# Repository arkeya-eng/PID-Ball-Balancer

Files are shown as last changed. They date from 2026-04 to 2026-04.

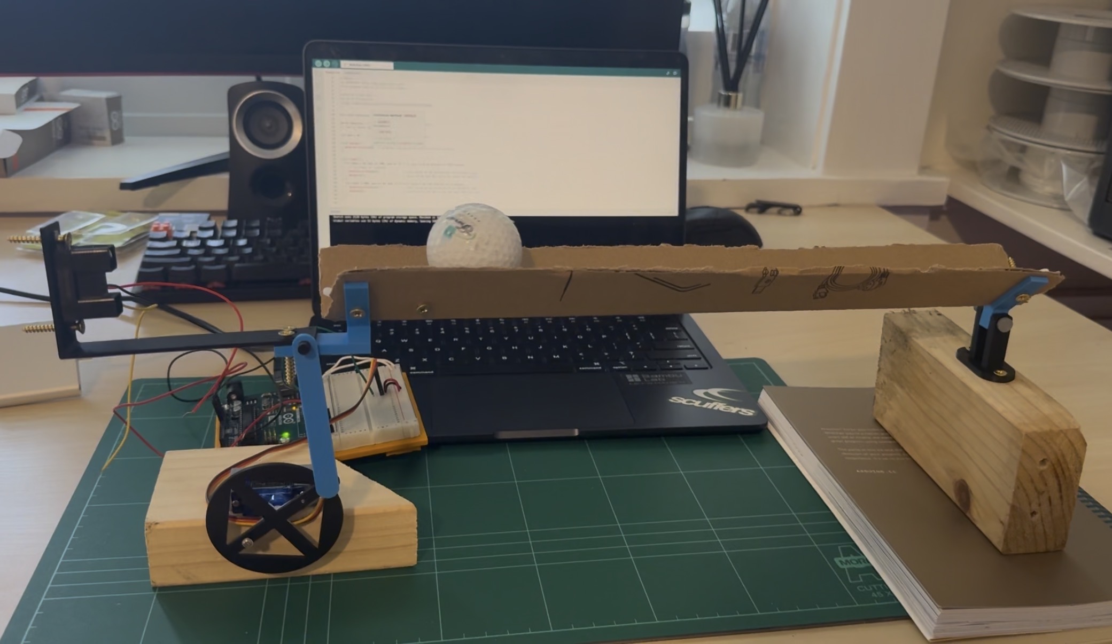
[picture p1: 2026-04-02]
media/Ver1.jpg

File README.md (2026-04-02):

# Golf Ball Balancing PID Controller

Designed and built a closed-loop control system that balances a golf ball on a beam in real time using an Arduino, IR distance sensor, and servo motor. Involved CAD design, 3D printing, sensor calibration, signal filtering, and PID controller tuning. Two full design iterations from prototype to final build.

Demo Video
<!-- Replace with an actual gif or remove this line if you don't have one yet -->

Final Build V2

## Overview

The system balances a golf ball at a target position on a beam by continuously reading the ball's position with an infrared distance sensor and adjusting the beam angle via a servo motor. A calibrated ADC-to-distance lookup table converts raw sensor readings to centimetres, and a PD control loop computes the required servo correction in real time.

Two full design iterations were completed — a rough prototype to validate the concept, followed by a refined final build with improved housing and sensor mounting.

## How It Works

1. **Sense** — Sharp IR sensor reads an analog voltage proportional to the ball's distance. Raw ADC values are smoothed with an exponential moving average (α = 0.2) and mapped to centimetres via a 16-point calibration table with linear interpolation.

2. **Compute** — A PD controller calculates the error between the target position and the current position. The derivative term damps oscillation. Output is clamped to a safe servo range (60°–180°).

3. **Actuate** — An Arduino Uno R3 writes the computed angle to a servo motor, which tilts the beam to drive the ball toward the setpoint.

## Hardware

| Component | Detail |
|---|---|
| Microcontroller | Arduino Uno R3 |
| Sensor | Sharp GP2Y0A21YK0F IR distance sensor |
| Actuator | YM-2765 servo motor |
| Housing | Custom designed in SolidWorks, 3D printed (PLA) |
| Ball | Standard golf ball |
| Structure | 2 x Steel (1m x 6mm) Rods|

## Repo Structure

```
PID-Ball-Balancer/
├── src/
│   └── main.ino          # Arduino source code
├── cad/
│   ├── prototype/        # V1 SolidWorks files
│   └── final/            # V2 SolidWorks files
├── media/
│   ├── demo.gif          # Short demo clip
│   ├── prototype.jpg     # Photo of V1 build
│   └── final.jpg         # Photo of V2 build
├── docs/
│   └── wiring.png        # Wiring diagram
└── README.md
```

## Wiring

```
Arduino Uno R3
├── A0  ←  IR sensor signal (yellow)
├── 5V  →  IR sensor VCC (red)
├── GND →  IR sensor GND (black)
├── D9  →  Servo signal (orange)
├── External Battery Holder (4xAA)  →  Servo VCC (red)
└── GND & External GND →  Servo GND (brown)
```

## Control Parameters

```
Kp = 0.2      // Proportional gain
Kd = 0.0      // Derivative gain (tuned out — system stable with P-only)
Setpoint = 46.0 cm from sensor
Neutral angle = 120°
Loop rate ≈ 100 Hz (10 ms delay)
```

## Build Process

**Prototype (V1)** — Quick proof-of-concept to validate sensor placement, servo torque, and basic control loop. Rough 3D-printed cradle, manual wiring.

**Final Build (V2)** — Redesigned housing with integrated sensor mount, cleaner cable routing, and tighter beam pivot. Improved stability and repeatability.

## Video

A build and tuning walkthrough video is included in the `/media` folder (or linked below once uploaded).

(https://youtu.be/jKo0sEahJNQ)

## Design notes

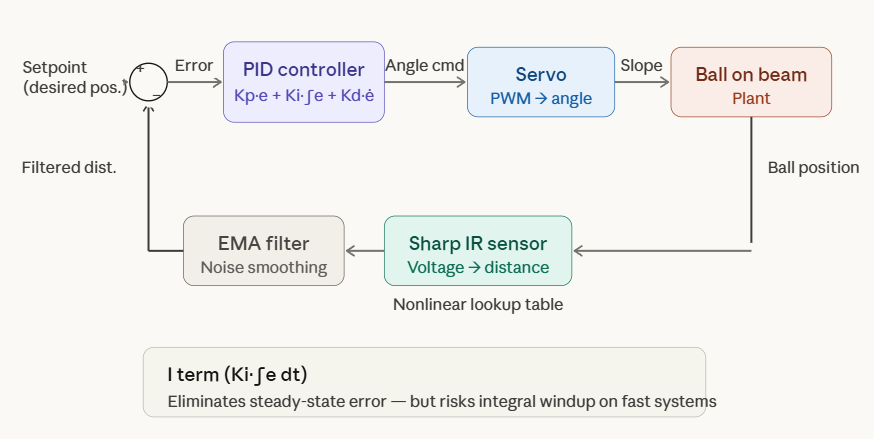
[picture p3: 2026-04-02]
docs/BlockDiagram.PNG

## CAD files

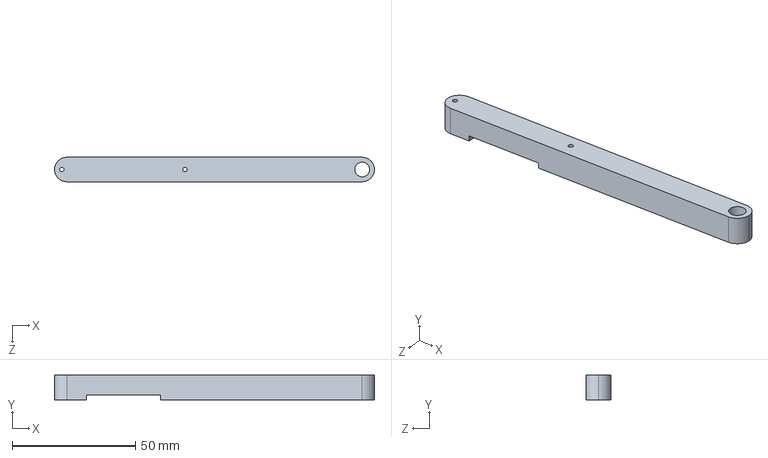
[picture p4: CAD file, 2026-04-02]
cad/ver2/ServoArm.SLDPRT
130.0 x 10.0 x 10.0 mm

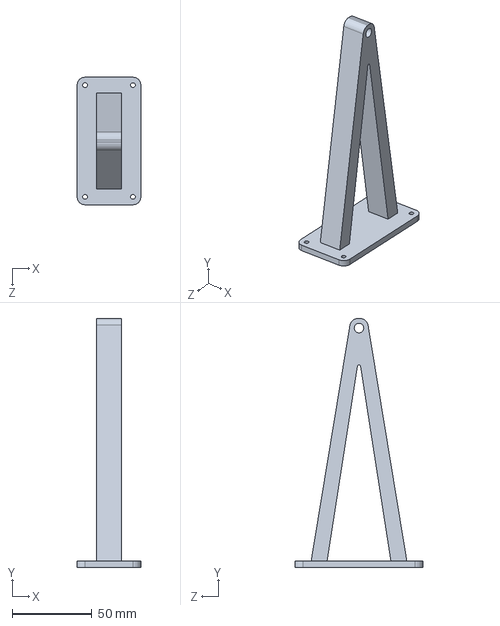
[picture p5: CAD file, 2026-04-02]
cad/ver2/BaseRight.SLDPRT
40.0 x 156.0 x 80.0 mm

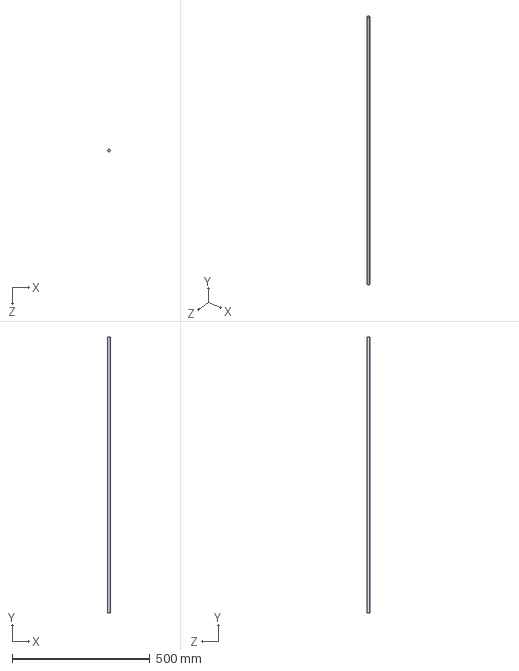
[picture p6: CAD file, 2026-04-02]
cad/ver2/Rod.SLDPRT
10.0 x 1000.0 x 10.0 mm

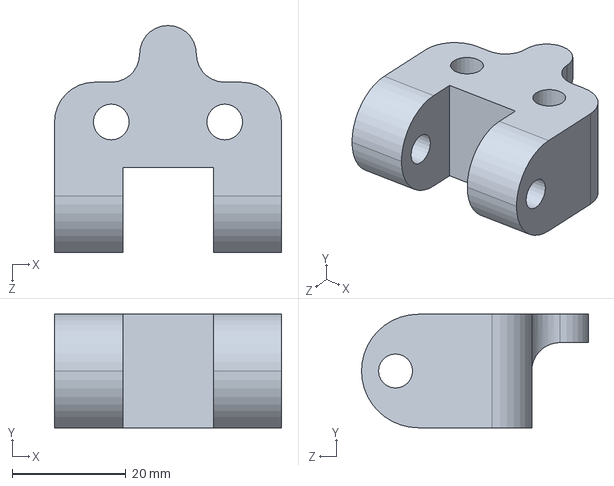
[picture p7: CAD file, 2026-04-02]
cad/ver2/RightHolder.SLDPRT
40.0 x 20.0 x 40.0 mm

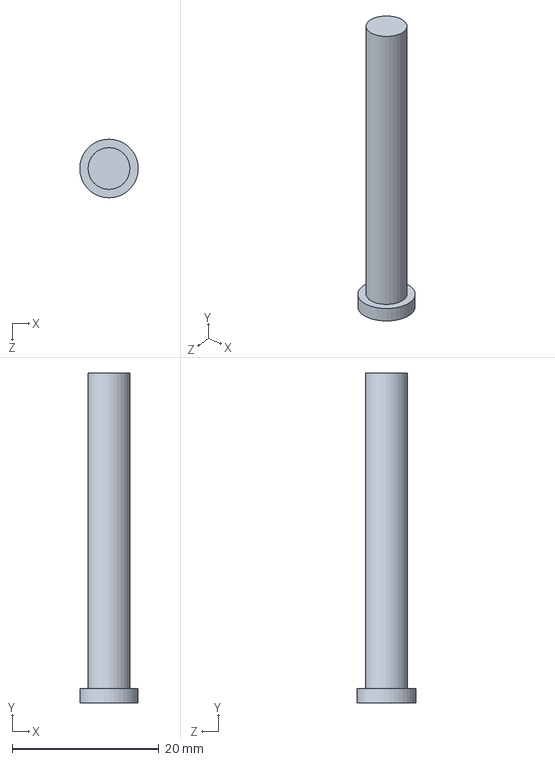
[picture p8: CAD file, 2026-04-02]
cad/ver2/PinRight.SLDPRT
7.97 x 45.0 x 8.00 mm

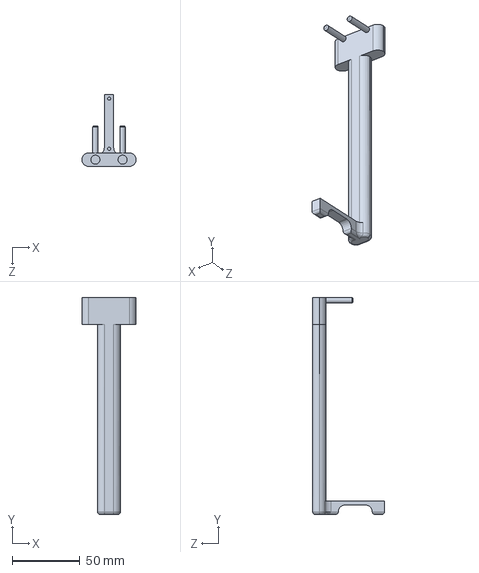
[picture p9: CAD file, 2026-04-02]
cad/ver2/IR_Holder.SLDPRT
40.0 x 160.0 x 53.0 mm

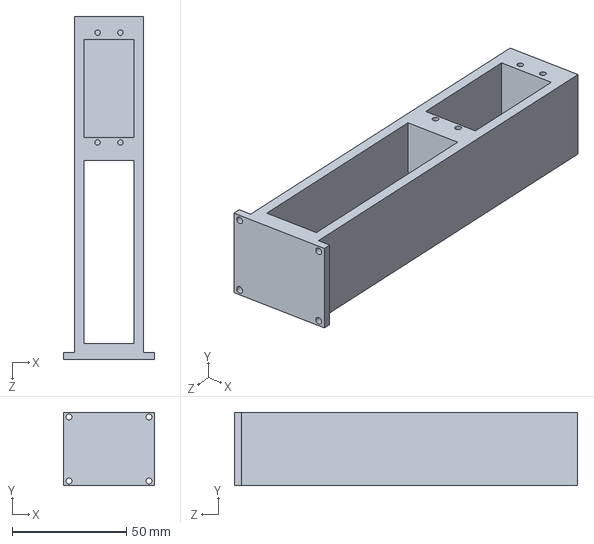
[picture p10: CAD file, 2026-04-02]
cad/ver2/MotorHousing.SLDPRT
40.0 x 32.0 x 150.0 mm

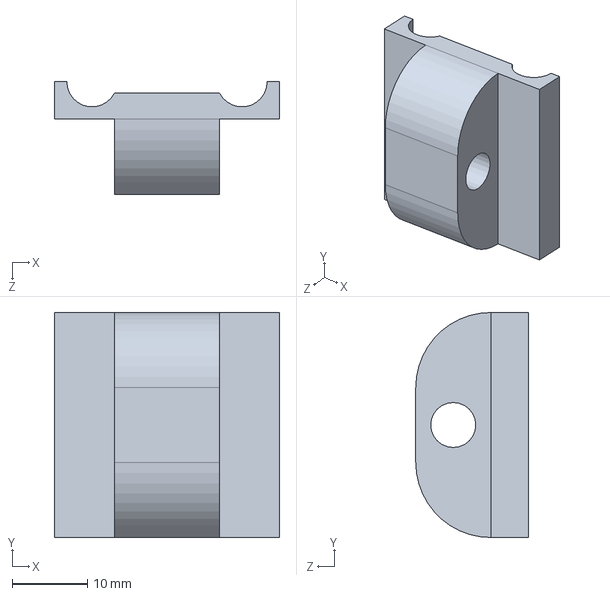
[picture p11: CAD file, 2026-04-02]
cad/ver2/RodHolder.SLDPRT
30.0 x 30.0 x 15.0 mm

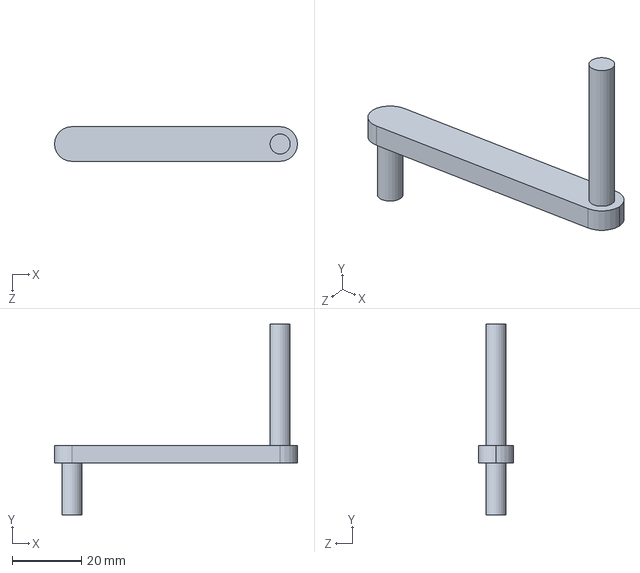
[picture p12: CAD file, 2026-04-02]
cad/ver2/Link.SLDPRT
70.0 x 55.0 x 10.0 mm

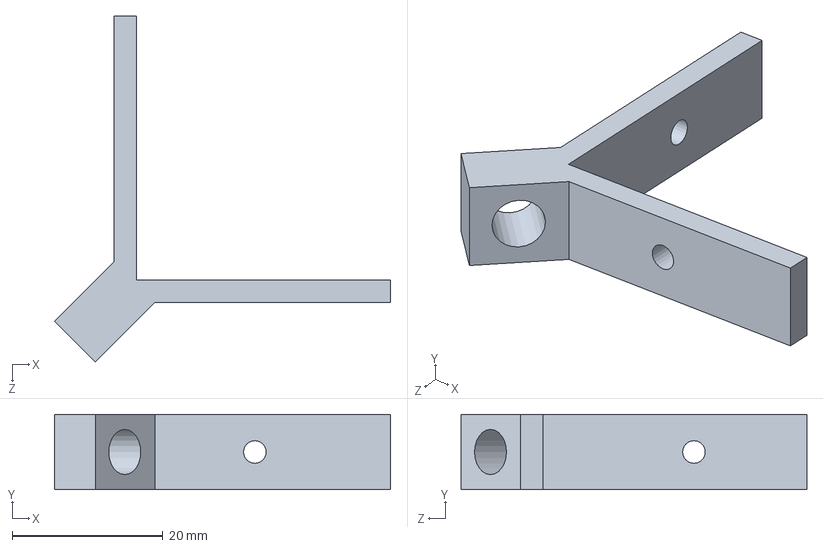
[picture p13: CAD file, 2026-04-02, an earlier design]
cad/ver1/RH.SLDPRT
44.6 x 10.0 x 45.9 mm

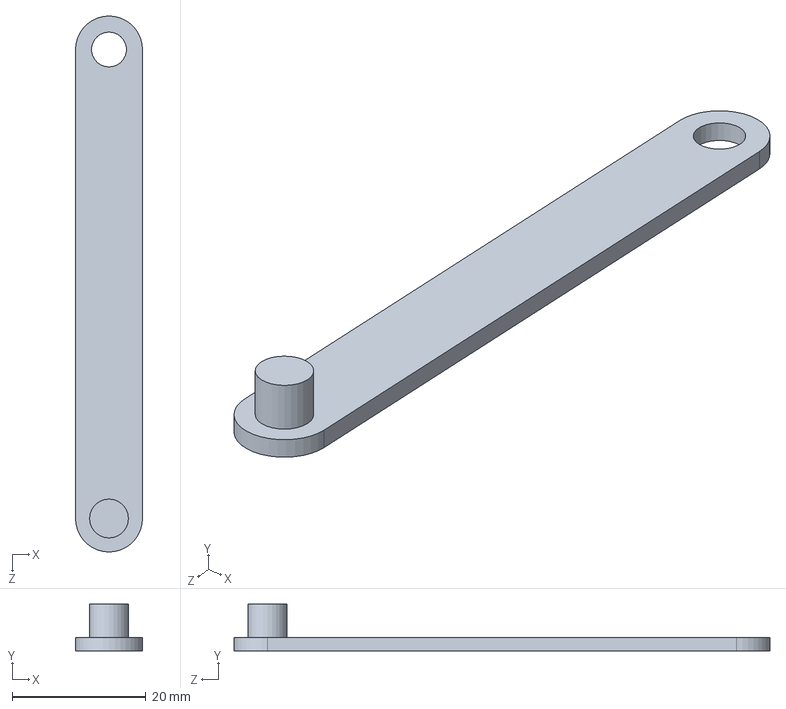
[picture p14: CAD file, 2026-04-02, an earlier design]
cad/ver1/Link.SLDPRT
10.0 x 7.00 x 80.0 mm

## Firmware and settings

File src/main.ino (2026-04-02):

#include <Servo.h>

const int irPin = A0;
const int servoPin = 9;
float smoothed = 0;
float alpha = 0.2;

Servo myServo;

// PID constants - tune these
float Kp = 0.2;
float Kd = 0.0;

float lastError = 0;
unsigned long lastTime = 0;

// Calibration lookup table: {ADC, distance_cm}
const int NUM_CAL_POINTS = 16;
const float calTable[NUM_CAL_POINTS][2] = {
  {583.69, 13.0}, {564.56, 15.0}, {533.65, 18.0}, {515.26, 20.0},
  {480.56, 23.0}, {432.95, 28.0}, {382.91, 33.0}, {339.87, 38.0},
  {297.84, 43.0}, {249.49, 53.0}, {219.55, 63.0}, {195.27, 73.0},
  {173.48, 83.0}, {151.77, 93.0}, {133.37, 103.0}, {115.29, 107.0}
};

float adcToDistance(float adc) {
  if (adc >= calTable[0][0]) return calTable[0][1];
  if (adc <= calTable[NUM_CAL_POINTS - 1][0]) return calTable[NUM_CAL_POINTS - 1][1];

  for (int i = 0; i < NUM_CAL_POINTS - 1; i++) {
    if (adc <= calTable[i][0] && adc >= calTable[i + 1][0]) {
      float ratio = (adc - calTable[i + 1][0]) / (calTable[i][0] - calTable[i + 1][0]);
      return calTable[i + 1][1] + ratio * (calTable[i][1] - calTable[i + 1][1]);
    }
  }
  return -1;
}

int computeServoAngle(float currentDist, float targetDist) {
  unsigned long now = millis();
  float dt = (now - lastTime) / 1000.0;
  if (dt <= 0) dt = 0.001;

  float error = targetDist - currentDist;
  float dError = (error - lastError) / dt;

  float output = Kp * error + Kd * dError;

  // 120 is roughly level — adjust to your beam's neutral angle
  int angle = 120 + (int)output;

  // Clamp to 60-180
  if (angle < 60) angle = 60;
  if (angle > 180) angle = 180;

  lastError = error;
  lastTime = now;

  return angle;
}

void setup() {
  Serial.begin(9600);
  myServo.attach(servoPin);
  myServo.write(120); // start level
  smoothed = analogRead(irPin);
  delay(500); // let servo settle
  lastTime = millis(); // after delay, not before
}

void loop() {

  int raw = analogRead(irPin);

  smoothed = alpha * raw + (1 - alpha) * smoothed;

  float distance = adcToDistance(smoothed);
  float ballPosition = distance - 15.0;

  float target = 46.0; // target position in cm from sensor — adjust this

  int servoAngle = computeServoAngle(distance, target);
  myServo.write(servoAngle);

  Serial.print("Pos:");
  Serial.print(ballPosition, 1);
  Serial.print(" Err:");
  Serial.print(target - distance, 1);
  Serial.print(" Servo:");
  Serial.println(servoAngle);

  delay(10);
}
